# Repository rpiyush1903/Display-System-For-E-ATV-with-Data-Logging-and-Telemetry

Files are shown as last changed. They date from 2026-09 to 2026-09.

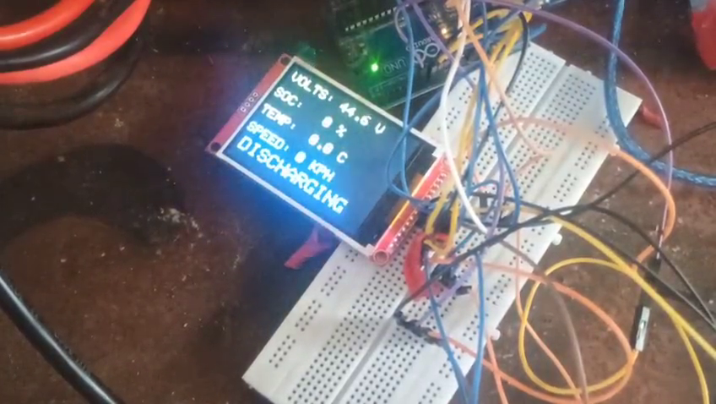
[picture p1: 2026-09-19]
display-test-img.png

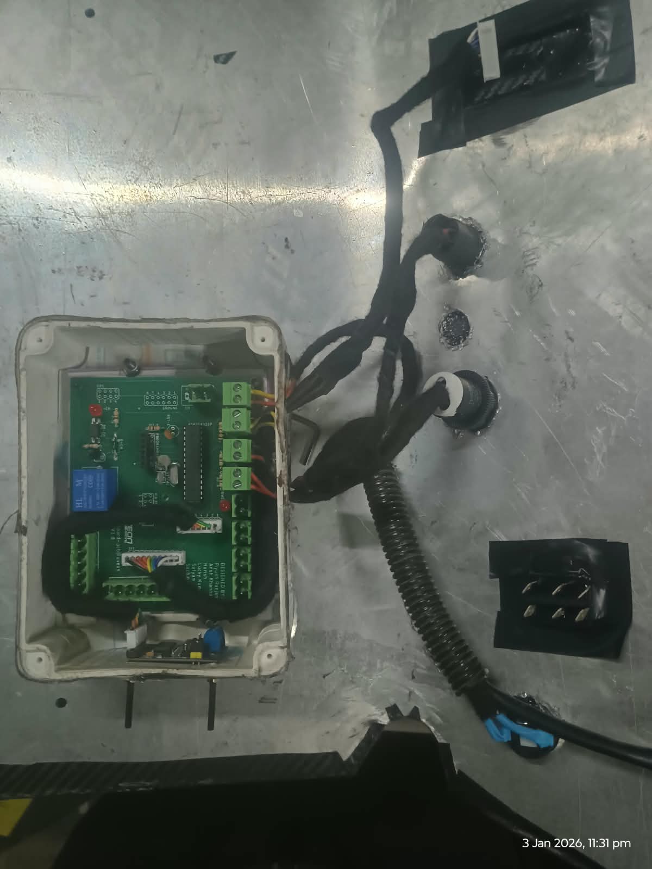
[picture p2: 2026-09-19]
dashboard-pcb-img.jpeg

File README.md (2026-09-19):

# Display and Safety System for an E-ATV Using CAN Bus Communication Protocol

## Description

This project is a custom dashboard and safety unit that I built for our electric All-Terrain Vehicle. It sits between the driver and the battery pack, doing two jobs at once: showing the driver what the battery is doing in real time, and acting as a safety switch that can cut power to the tractive system if something goes wrong.

The unit reads data directly from our JBD Battery Management System over CAN bus and shows it on a TFT display mounted on the dash Pack voltage, current draw (or charge current), state of charge (SoC), and pack temperature. It also drives a relay that can de-energize the main contactors, either automatically when a fault is detected or manually during testing.

Everything runs on an ATMega328P microcontroller, with an MCP2515 module handling the CAN interface, and the whole thing is built onto a custom PCB so it can survive the vibration and environment of off-road racing.

## Why I Built This

When you're racing an e-ATV, the battery pack is both the thing that makes the vehicle go and the thing most likely to cause a serious problem if it's mismanaged. 

**Charging and pack safety.** A lithium pack that's overcharged, over-discharged, or running too hot can fail badly, and on a race vehicle there isn't always someone watching a laptop connected to the BMS. I wanted a hardware safety interlock that sits close to the pack and can isolate it the moment something crosses a safe limit, rather than relying on the driver to notice a problem and react in time. 

Also there should be an hardware safety interlock to prevent simultaneous charging and operation of vehicle ( battery should not get charged when vehicle is ready to drive)

**Driver awareness.** Beyond safety, the driver genuinely needs to know what the battery is doing while driving — voltage, current draw, temperature, and remaining charge. Without this, the driver is flying blind: they don't know if they're pushing the pack too hard, how much charge is left for the rest of a heat, or whether the pack is running hotter than it should. A simple, readable display on the dash solves that, and having it double as a diagnostic tool during pit stops and testing was a natural extension.

Putting both of these on one board also meant fewer separate systems, less wiring, and reduced clutter in the vehicle.

## How I Did It

I started from the JBD BMS's CAN output, since that's already generating the data I needed I didn't want to add extra sensors when the BMS was already measuring everything.

**Reading the BMS over CAN.** I used an MCP2515 CAN controller (SPI interface) to talk to the BMS at 500kbps. The BMS broadcasts on a few standard IDs, and I parsed the ones that matter for the dashboard:

| CAN ID | Data |
| :--- | :--- |
| `0x100` | Pack voltage and current |
| `0x101` | State of charge 
| `0x105` | Pack temperature 

Since the BMS doesn't just keep streaming data forever on its own, I have the microcontroller send a small keep-alive frame (`0x5A`) periodically to the BMS's target IDs, which keeps the connection alive and the data flowing.

**Showing it to the driver.** The parsed values get pushed to a TFT display using the `TFT_eSPI` library, connected over the hardware SPI bus. I set up `User_Setup.h` to match the exact driver and pinout of the display I used, since getting this wrong is the most common reason the display doesn't come up at all.

**The safety side.** A relay is wired to a dedicated GPIO pin (pin 5 in the diagnostic build). HIGH keeps the relay de-energized and power flowing normally; pulling it LOW cuts power by opening the main contactors. This lets the firmware isolate the pack automatically if a reading goes outside safe limits, and it also gives me a manual way to cut power during bench testing without touching the high-voltage wiring directly.

**Putting it on one board.** Once the logic was working on a breadboard, I moved everything onto a custom PCB. The main reason was reliability . An ATV shakes a lot, and loose header connections are a common failure point. I also made sure to physically separate the high-speed SPI lines (display and CAN) from the relay switching lines on the layout, since the relay can introduce electrical noise that was causing flicker on the display and occasional glitches on the CAN bus during earlier tests.

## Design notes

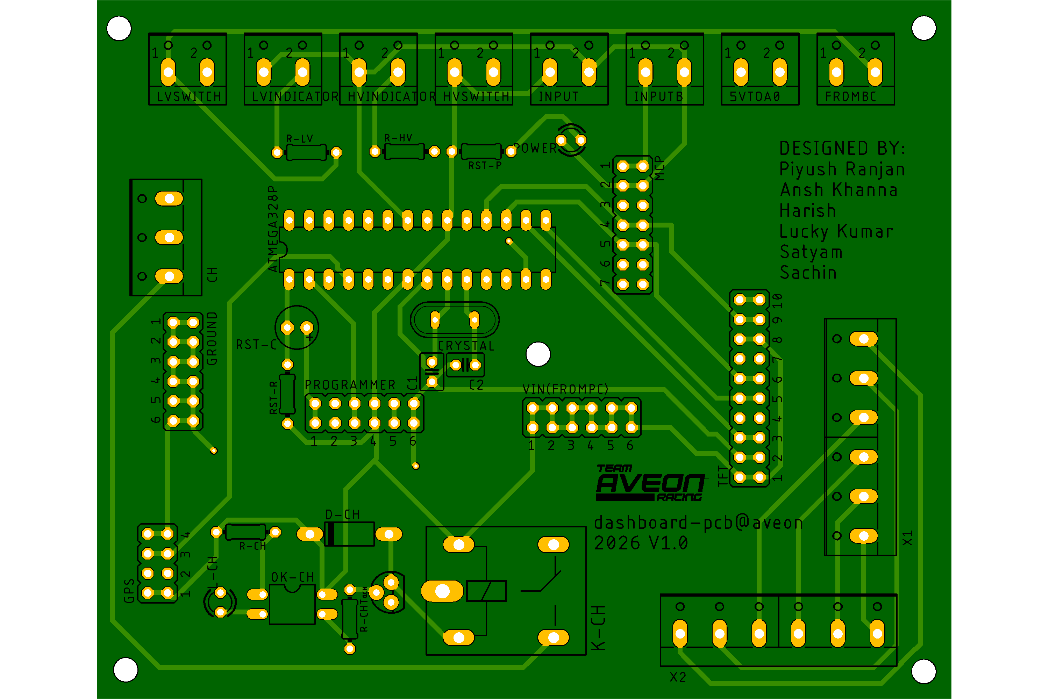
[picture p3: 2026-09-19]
DASHBOARDTOP.png

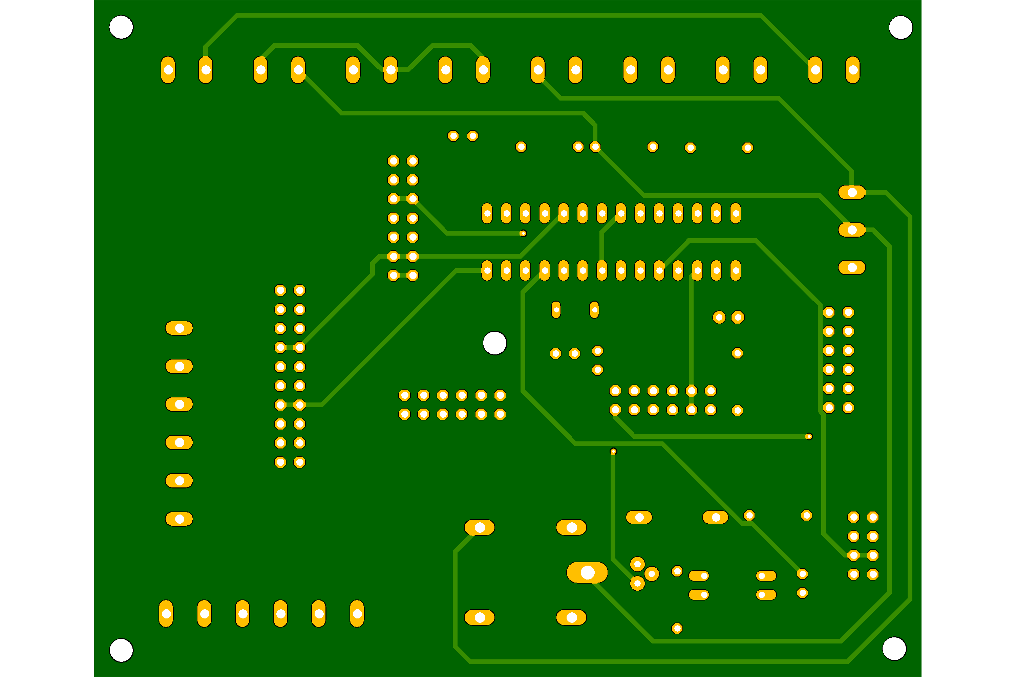
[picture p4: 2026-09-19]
DASHBOARDBOTTOM.png

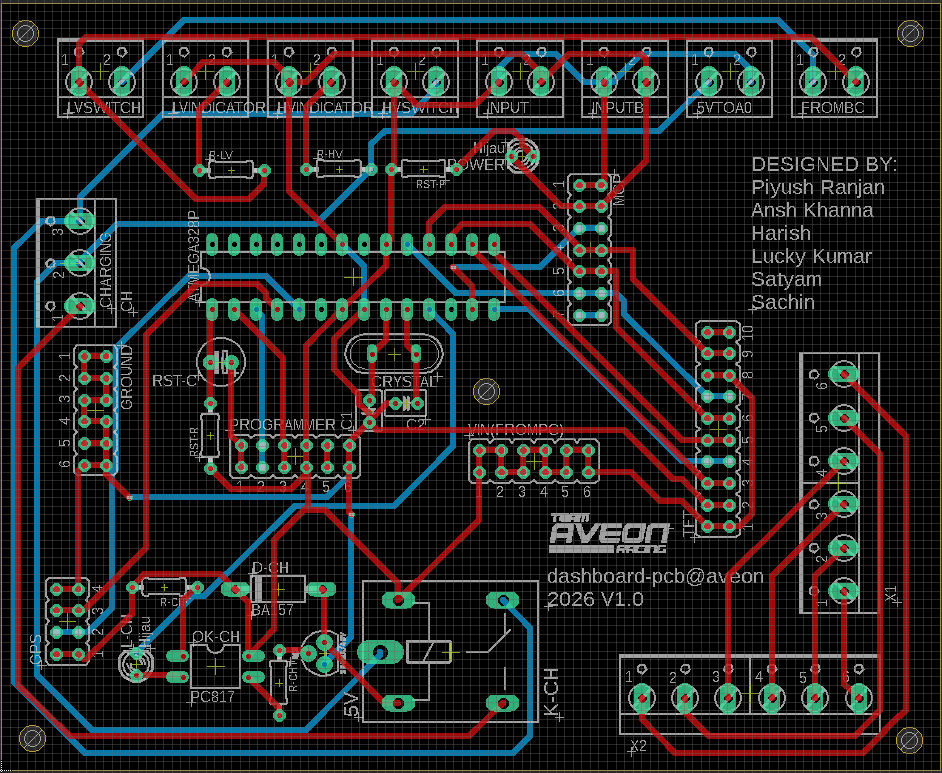
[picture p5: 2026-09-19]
pcb-brdfile.png

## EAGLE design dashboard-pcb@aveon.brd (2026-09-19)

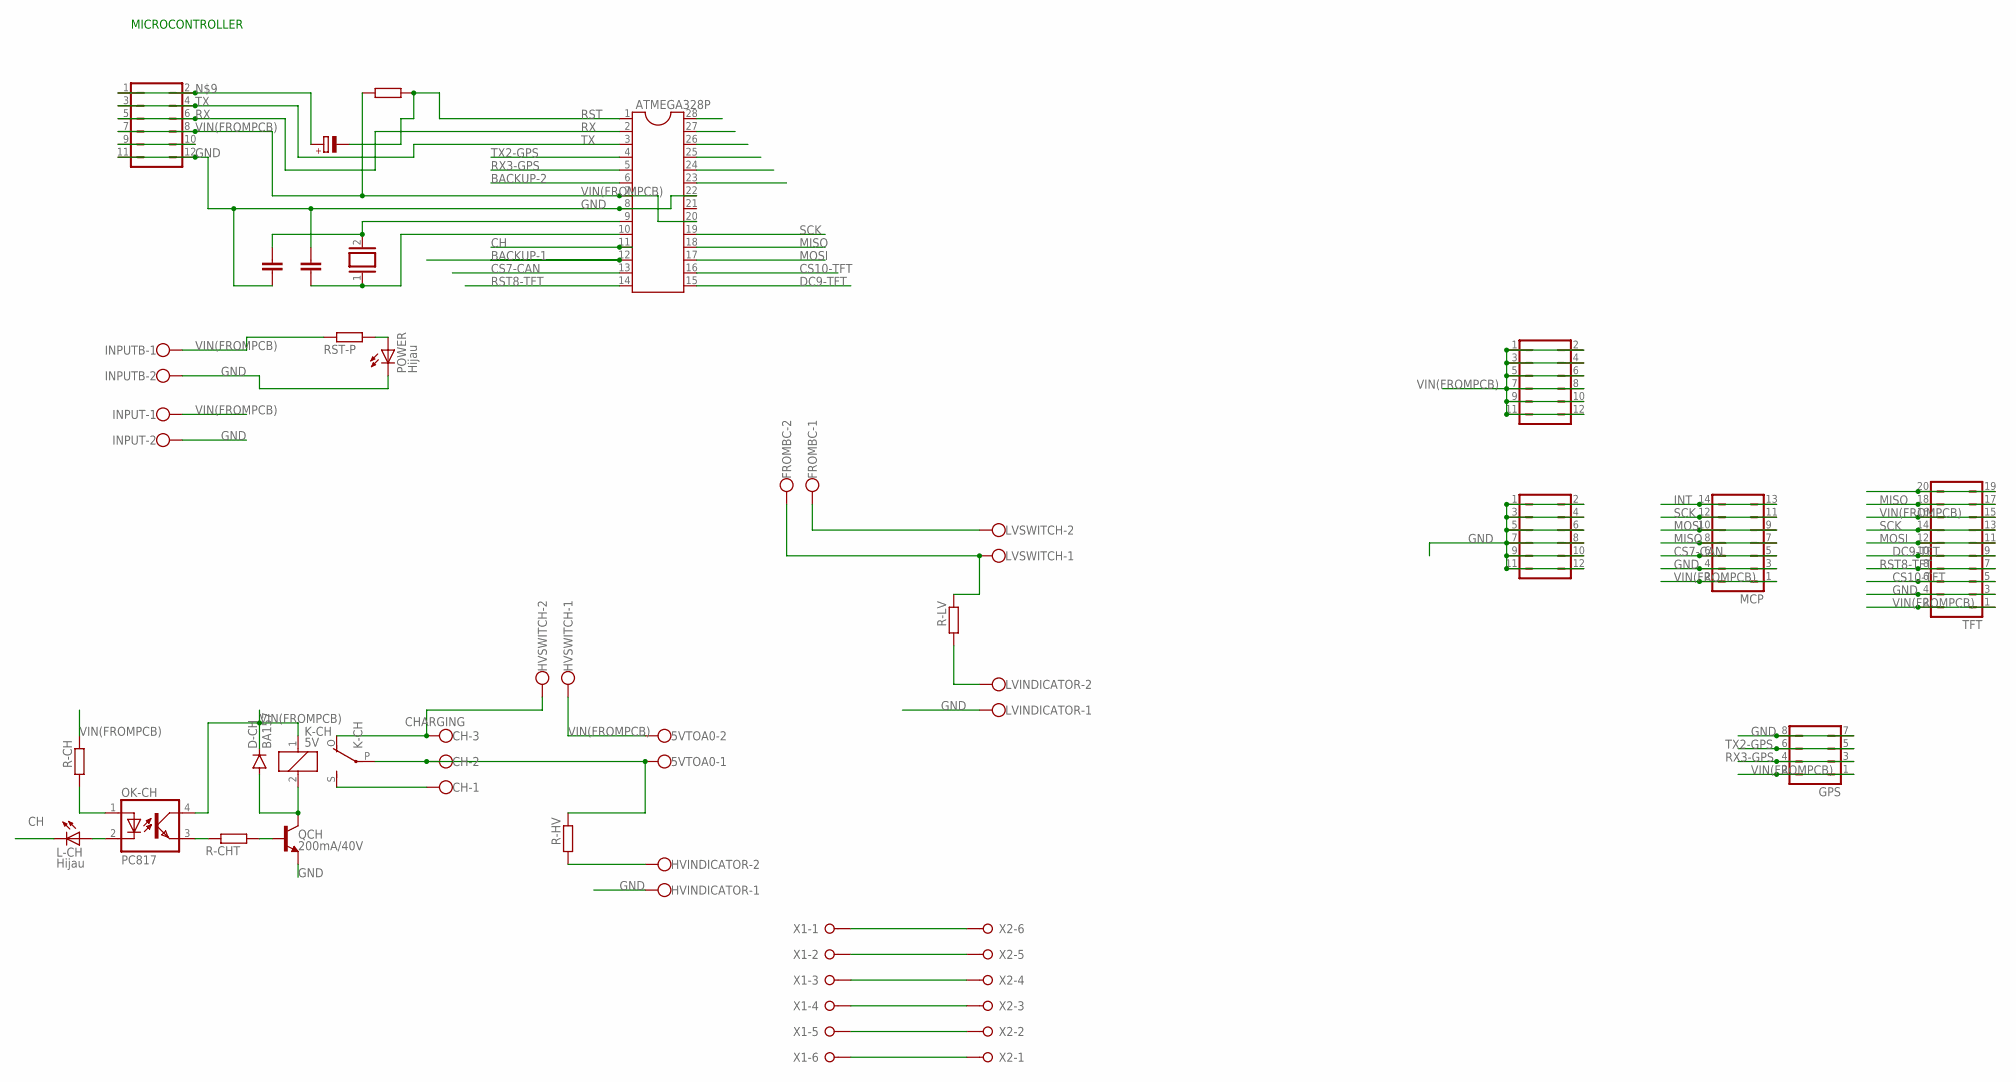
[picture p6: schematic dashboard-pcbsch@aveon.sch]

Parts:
5VTOA0: W237-102
ATMEGA328P: DIL28-3
C1, C2: C-EU025-030X050; C025-030X050
CH: CHARGING; W237-103
CRYSTAL: XTAL/S; QS
D-CH: BA157; P1-10
FROMBC: W237-102
GPS: JP4Q
GROUND: JP6Q
HVINDICATOR: W237-102
HVSWITCH: W237-102
INPUT: W237-102
INPUTB: W237-102
K-CH: 5V; ZF112
L-CH: Hijau; LED3MM
LVINDICATOR: W237-102
LVSWITCH: W237-102
MCP: JP7Q
OK-CH: PC817; DIL04
POWER: Hijau; LED3MM
PROGRAMMER: JP6Q
QCH: 200mA/40V; TO-92
R-CH: R-EU_0204/7; 0204/7
R-CHT: R-EU_0204/7; 0204/7
R-HV: R-EU_0204/7; 0204/7
R-LV: R-EU_0204/7; 0204/7
RST-C: CPOL-EUE2.5-6; E2,5-6
RST-P: R-EU_0204/7; 0204/7
RST-R: R-EU_0204/7; 0204/7
TFT: JP10Q
VIN(FROMPC): JP6Q
X1, X2: W237-06P; W237-6P

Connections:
BACKUP-1: ATMEGA328P.12
BACKUP-2: ATMEGA328P.6
CH: ATMEGA328P.11, L-CH.K (C)
CS7-CAN: ATMEGA328P.13, MCP.5, MCP.6
CS10-TFT: ATMEGA328P.16, TFT.5, TFT.6
DC9-TFT: ATMEGA328P.15, TFT.9, TFT.10
GND: ATMEGA328P.8, ATMEGA328P.22, C1.1, C2.2, GPS.7, GPS.8, GROUND.1, GROUND.2, GROUND.3, GROUND.4, GROUND.5, GROUND.6, GROUND.7, GROUND.8, GROUND.9, GROUND.10, GROUND.11, GROUND.12, HVINDICATOR.1, INPUT.2, INPUTB.2, LVINDICATOR.1, MCP.3, MCP.4, POWER.K (C), PROGRAMMER.11, PROGRAMMER.12, QCH.1 (E), TFT.3, TFT.4
INT: MCP.13, MCP.14
MISO: ATMEGA328P.18, MCP.7, MCP.8, TFT.17, TFT.18
MOSI: ATMEGA328P.17, MCP.9, MCP.10, TFT.11, TFT.12
unnamed: POWER.A, RST-P.1
unnamed: FROMBC.1, LVSWITCH.2
unnamed: FROMBC.2, LVSWITCH.1, R-LV.2
unnamed: LVINDICATOR.2, R-LV.1
unnamed: PROGRAMMER.1, PROGRAMMER.2, RST-C.+
unnamed: ATMEGA328P.9, C1.2, CRYSTAL.2
unnamed: X1.1, X2.6
unnamed: X1.2, X2.5
unnamed: X1.3, X2.4
unnamed: X1.4, X2.3
unnamed: L-CH.A, OK-CH.2 (C)
unnamed: CH.3, HVSWITCH.2, K-CH.O
unnamed: OK-CH.1 (A), R-CH.1
unnamed: OK-CH.3 (EMIT), R-CHT.2
unnamed: D-CH.A, K-CH.2, QCH.3 (C)
unnamed: QCH.2 (B), R-CHT.1
unnamed: CH.1, K-CH.S
unnamed: 5VTOA0.1, CH.2, K-CH.P, R-HV.2
unnamed: X1.5, X2.2
unnamed: HVINDICATOR.2, R-HV.1
unnamed: X1.6, X2.1
unnamed: TFT.19, TFT.20
unnamed: ATMEGA328P.10, C2.1, CRYSTAL.1
unnamed: PROGRAMMER.9, PROGRAMMER.10
RST: ATMEGA328P.1, RST-C.-, RST-R.2
RST8-TFT: ATMEGA328P.14, TFT.7, TFT.8
RX: ATMEGA328P.2, PROGRAMMER.5, PROGRAMMER.6
RX3-GPS: ATMEGA328P.5, GPS.3, GPS.4
SCK: ATMEGA328P.19, MCP.11, MCP.12, TFT.13, TFT.14
TX: ATMEGA328P.3, PROGRAMMER.3, PROGRAMMER.4
TX2-GPS: ATMEGA328P.4, GPS.5, GPS.6
VIN(FROMPCB): 5VTOA0.2, ATMEGA328P.7, ATMEGA328P.20, D-CH.C, GPS.1, GPS.2, HVSWITCH.1, INPUT.1, INPUTB.1, K-CH.1, MCP.1, MCP.2, OK-CH.4 (COL), PROGRAMMER.7, PROGRAMMER.8, R-CH.2, RST-P.2, RST-R.1, TFT.1, TFT.2, TFT.15, TFT.16, VIN(FROMPC).1, VIN(FROMPC).2, VIN(FROMPC).3, VIN(FROMPC).4, VIN(FROMPC).5, VIN(FROMPC).6, VIN(FROMPC).7, VIN(FROMPC).8, VIN(FROMPC).9, VIN(FROMPC).10, VIN(FROMPC).11, VIN(FROMPC).12

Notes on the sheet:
MICROCONTROLLER

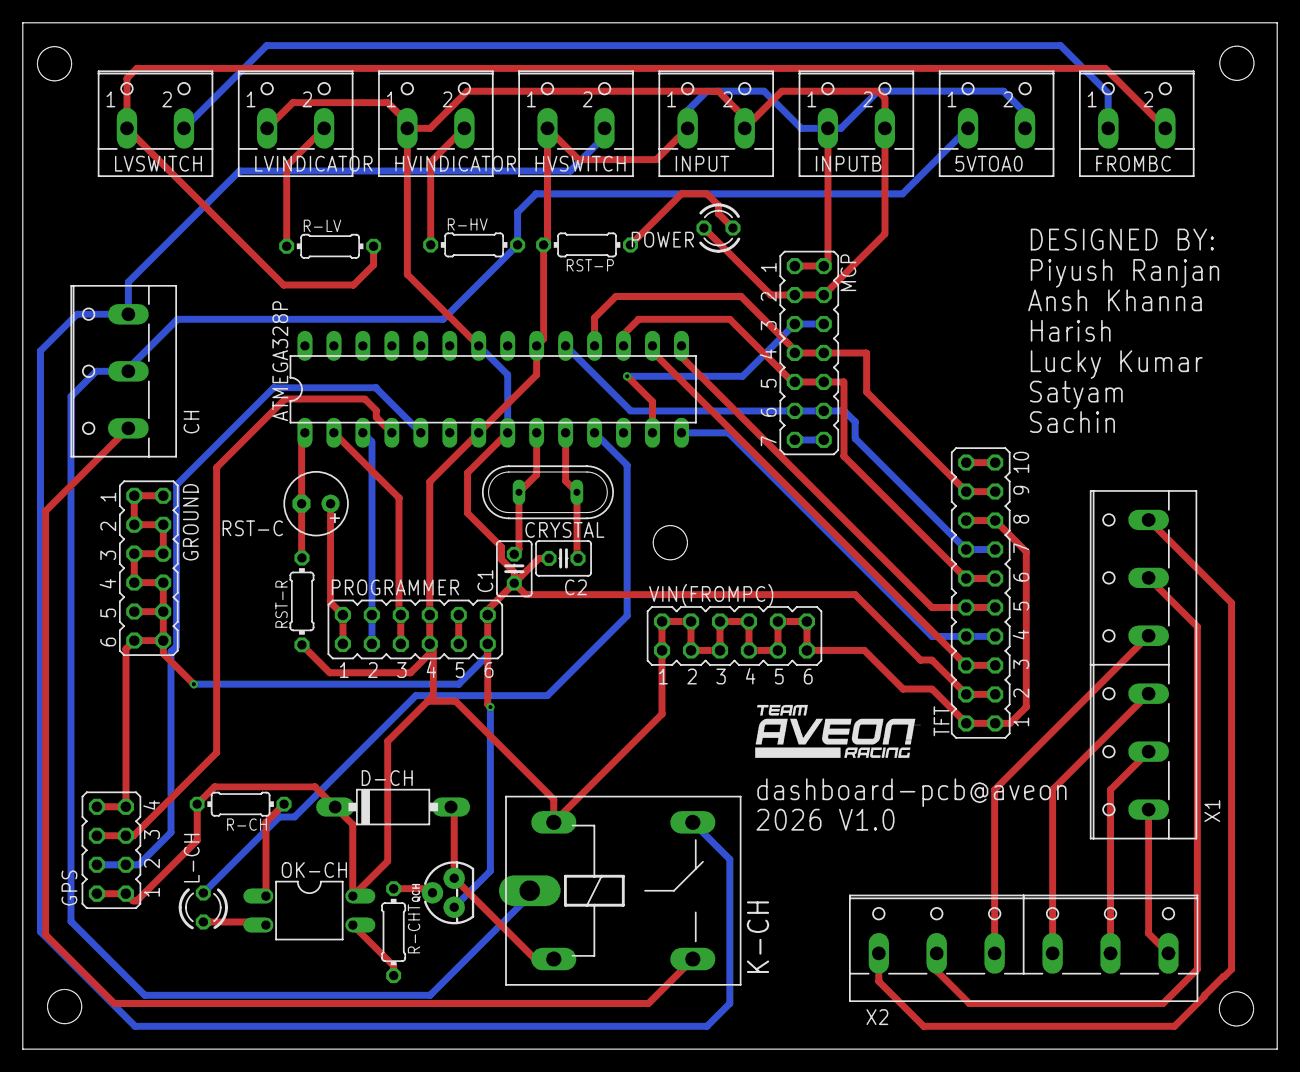
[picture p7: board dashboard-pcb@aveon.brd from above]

Board: 2 copper layers, 110.0 x 90.0 mm, 34 parts (0 on the bottom side), 40 nets.

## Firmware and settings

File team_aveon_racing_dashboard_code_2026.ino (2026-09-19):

/*
  Aveon Racing - JBD BMS Dashboard (2.8" CENTERED VERSION)
  
  - Controller: ATmega328P (Arduino Uno)
  - Display: ST7789 / ILI9341 (320x240 Landscape)
  - CAN Bus: MCP2515 (CS Pin 7)
  - Safety: Relay on Pin 5 (Active LOW)
  
  UPDATES:
  1. Centered Logo for 320px wide screens.
  2. Colors: TEAM/RACING = White, AVEON = Dark Green.
  3. Dashboard layout expanded to fill 2.8" screen.
*/

#include <SPI.h>
#include <TFT_eSPI.h>
#include <mcp_can.h>
#include <avr/pgmspace.h>

// --- Load Custom Font ---
#define RACING_FONT &FreeSansBold12pt7b 

// --- Pin Definitions ---
const int MCP_CS_PIN = 7;
const int RELAY_PIN  = 5; // Safety Relay (Active LOW)

// --- CAN IDs ---
#define CAN_ID_VOLT_CURR 0x100 
#define CAN_ID_SOC       0x101
#define CAN_ID_TEMP      0x105

// --- Global Objects ---
TFT_eSPI tft = TFT_eSPI();
MCP_CAN mcp2515(MCP_CS_PIN);
SPISettings mcpSPISettings(10000000, MSBFIRST, SPI_MODE0);

// --- Data Variables ---
float rawVoltage = 0.0;
float smoothedVoltage = 0.0;
float current = 0.0;
int   soc = 0;
float tempNTC1 = 0.0;
bool  isCharging = false;
bool  newDataBMS = false;

// --- Screen Constants ---
// 2.8" Screens are usually 320x240 in Landscape
const int SCREEN_W = 320;
const int SCREEN_H = 240;
int centerX = SCREEN_W / 2; // Will be calculated in setup

// --- Layout Constants ---
const int BORDER_COLOR = TFT_CYAN;
const int TEXT_COLOR   = TFT_WHITE;
const int ROW_VOLTS = 50; 
const int ROW_SOC   = 110;
const int ROW_TEMP  = 170;

// Adjusted columns for wider 320px screen
const int COL_LABEL = 20;  // Labels slightly indented
const int COL_DATA  = 160; // Data numbers moved to the right side

// --- Timing ---
unsigned long lastCANRequest = 0;
unsigned long lastDisplayUpdate = 0;
const long canRequestInterval = 1000;   
const long displayUpdateInterval = 250; 

// ==========================================
//   HELPER FUNCTIONS 
// ==========================================
void drawStaticInterface();
void updateDisplayValues();
void parseBMSData(long id, unsigned char data[8]);
void updateSafetyRelay();

// ==========================================
//   MAIN SETUP
// ==========================================
void setup() {
  // 1. Init Relay (Fail-Safe: HIGH)
  pinMode(RELAY_PIN, OUTPUT);
  digitalWrite(RELAY_PIN, HIGH); 

  // 2. Init TFT
  tft.init();
  tft.setRotation(1); // Landscape
  tft.fillScreen(TFT_BLACK);
  
  // Calculate true center based on actual screen width
  centerX = tft.width() / 2;

  // =========================================
  //   STARTUP SEQUENCE (CENTERED)
  // =========================================
  
  tft.setTextDatum(MC_DATUM); // Set alignment to Middle Center
  
  // Draw "TEAM" (Small, White)
  tft.setTextSize(1);
  tft.setFreeFont(RACING_FONT);
  tft.setTextColor(TFT_WHITE, TFT_BLACK); 
  tft.drawString("TEAM", centerX, 60);

  // Draw "AVEON" (Large, Dark Green)
  tft.setTextSize(2); // Double size
  tft.setTextColor(TFT_DARKGREEN, TFT_BLACK);
  tft.drawString("AVEON", centerX, 100);

  // Draw "RACING" (Small, White)
  tft.setTextSize(1);
  tft.setTextColor(TFT_WHITE, TFT_BLACK);
  tft.drawString("RACING", centerX, 140);
  
  // Draw Init Status
  tft.setFreeFont(NULL); // Standard font
  tft.setTextSize(1);
  tft.setTextColor(TFT_WHITE, TFT_BLACK);
  tft.drawString("Initializing CAN Bus...", centerX, 180);

  // 3. Init CAN
  SPI.beginTransaction(mcpSPISettings);
  while (mcp2515.begin(MCP_ANY, CAN_500KBPS, MCP_8MHZ) != CAN_OK) {
    SPI.endTransaction();
    
    // Update status (Centered)
    tft.fillRect(0, 170, tft.width(), 30, TFT_BLACK);
    tft.setTextColor(TFT_RED, TFT_BLACK);
    tft.drawString("CAN FAIL. Retrying...", centerX, 180);
    
    delay(500);
    SPI.beginTransaction(mcpSPISettings);
  }
  SPI.endTransaction();
  
  SPI.beginTransaction(mcpSPISettings);
  mcp2515.setMode(MCP_NORMAL);
  SPI.endTransaction();

  // Show Success
  tft.fillRect(0, 170, tft.width(), 30, TFT_BLACK);
  tft.setTextColor(TFT_GREEN, TFT_BLACK);
  tft.drawString("CAN CONNECTED!", centerX, 180);
  delay(1500); 
  
  // =========================================
  //   START DASHBOARD
  // =========================================
  tft.fillScreen(TFT_BLACK);
  tft.setTextDatum(TL_DATUM); // Reset alignment to Top-Left for dashboard
  drawStaticInterface();
}

// ==========================================
//   MAIN LOOP
// ==========================================
void loop() {
  unsigned long now = millis();

  // --- TASK 1: BMS Request ---
  if (now - lastCANRequest >= canRequestInterval) {
    lastCANRequest = now;
    byte msg[1] = {0x5A};
    SPI.beginTransaction(mcpSPISettings);
    mcp2515.sendMsgBuf(CAN_ID_VOLT_CURR, 0, 1, msg);
    delay(5); 
    mcp2515.sendMsgBuf(CAN_ID_SOC, 0, 1, msg);
    delay(5);
    mcp2515.sendMsgBuf(CAN_ID_TEMP, 0, 1, msg);
    SPI.endTransaction();
  }

  // --- TASK 2: Receive CAN ---
  SPI.beginTransaction(mcpSPISettings);
  if (mcp2515.checkReceive() == CAN_MSGAVAIL) {
    long canId;
    unsigned char len;
    unsigned char buf[8];
    mcp2515.readMsgBuf(&canId, &len, buf);
    parseBMSData(canId, buf);
    newDataBMS = true;
  }
  SPI.endTransaction();

  // --- TASK 3: Safety Logic ---
  updateSafetyRelay();

  // --- TASK 4: Update Display ---
  if (now - lastDisplayUpdate >= displayUpdateInterval) {
    lastDisplayUpdate = now;
    
    if(rawVoltage > 1.0) { 
        smoothedVoltage = (smoothedVoltage * 0.8) + (rawVoltage * 0.2);
    }
    
    updateDisplayValues();
  }
}

// ==========================================
//   FUNCTIONS
// ==========================================

void updateSafetyRelay() {
  if (isCharging) {
    digitalWrite(RELAY_PIN, LOW); 
  } else {
    digitalWrite(RELAY_PIN, HIGH);
  }
}

void parseBMSData(long id, unsigned char data[8]) {
  switch (id) {
    case CAN_ID_VOLT_CURR:
      rawVoltage = ((data[0] << 8) | data[1]) * 0.01;
      current = (int16_t)((data[2] << 8) | data[3]) * 0.01;
      
      if (current > 0.5) {
        isCharging = true;
      } else {
        isCharging = false;
      }
      break;

    case CAN_ID_SOC:
      soc = (data[4] << 8) | data[5];
      break;
      
    case CAN_ID_TEMP:
      float tempK = ((data[0] << 8) | data[1]) * 0.1;
      tempNTC1 = tempK - 273.15;
      break;
  }
}

void drawStaticInterface() {
  // Draw Borders (Dynamic Width)
  int w = tft.width();
  int h = tft.height();
  
  tft.drawRect(0, 0, w, h, BORDER_COLOR);
  tft.drawRect(1, 1, w-2, h-2, BORDER_COLOR); 

  // Draw Separator Lines
  tft.drawLine(10, 65, w-10, 65, TFT_DARKGREY);  
  tft.drawLine(10, 125, w-10, 125, TFT_DARKGREY); 
  tft.drawLine(10, 185, w-10, 185, TFT_DARKGREY); 

  // Draw Labels
  tft.setTextColor(TFT_LIGHTGREY, TFT_BLACK); 
  tft.setFreeFont(RACING_FONT); 
  tft.setTextSize(1);

  tft.setCursor(COL_LABEL, ROW_VOLTS);
  tft.print("VOLT");
  tft.setCursor(COL_LABEL, ROW_SOC);
  tft.print("SOC");
  tft.setCursor(COL_LABEL, ROW_TEMP);
  tft.print("TEMP");
}

void updateDisplayValues() {
  tft.setFreeFont(RACING_FONT); 
  tft.setTextColor(TEXT_COLOR, TFT_BLACK);
  tft.setTextSize(1);

  // Update Voltage
  // Erase box is wider now for 320px screen
  tft.fillRect(COL_DATA, ROW_VOLTS - 25, 140, 30, TFT_BLACK);
  tft.setCursor(COL_DATA, ROW_VOLTS);
  tft.print(smoothedVoltage, 1);
  tft.print(" V");

  // Update SOC
  tft.fillRect(COL_DATA, ROW_SOC - 25, 140, 30, TFT_BLACK);
  if (soc < 20) tft.setTextColor(TFT_RED, TFT_BLACK);
  else tft.setTextColor(TFT_WHITE, TFT_BLACK);
  tft.setCursor(COL_DATA, ROW_SOC);
  tft.print(soc);
  tft.print(" %");

  // Update Temp
  tft.fillRect(COL_DATA, ROW_TEMP - 25, 140, 30, TFT_BLACK);
  if (tempNTC1 > 55) tft.setTextColor(TFT_RED, TFT_BLACK);
  else tft.setTextColor(TFT_WHITE, TFT_BLACK);
  tft.setCursor(COL_DATA, ROW_TEMP);
  tft.print(tempNTC1, 0);
  tft.print(" C");

  // Update Status
  tft.fillRect(10, 195, tft.width()-20, 40, TFT_BLACK);
  tft.setTextDatum(MC_DATUM);  
  
  if (isCharging) {
    tft.setTextColor(TFT_GREEN, TFT_BLACK);
    tft.drawString("CHARGING", centerX, 215); // Centered
  } else {
    tft.setTextColor(TFT_ORANGE, TFT_BLACK);
    tft.drawString("DISCHARGING", centerX, 215); // Centered
  }
  tft.setTextDatum(TL_DATUM); 
}

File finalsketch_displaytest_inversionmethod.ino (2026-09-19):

/*
  TFT_eSPI Library Test for ST7789 (320x240)

  This sketch will run all tests in landscape mode.
  It relies on your User_Setup.h file being
  correctly configured.
*/
#include <SPI.h>
#include <TFT_eSPI.h> // Include the configured library

// Create a TFT_eSPI object
TFT_eSPI tft = TFT_eSPI();

void setup() {
  Serial.begin(9600);
  Serial.println("TFT_eSPI ST7789 Test (Landscape)");

  tft.init(); // Initialize the library
  
  // --- LANDSCAPE MODE ---
  // setRotation(1) or setRotation(3) will give 320x240.
  // If this is upside-down, change 1 to 3.
  tft.setRotation(1); 

  // --- USER REQUEST: Set background to BLACK ---
  // This should now work with TFT_INVERSION_OFF
  tft.fillScreen(TFT_BLACK); 
  Serial.println("Screen set to black.");
  delay(500);

  // --- Start Test Sequence ---

  // Test 1: Text
  testText();
  delay(2000);

  // Test 2: Lines
  testLines(TFT_CYAN);
  delay(1000);

  // Test 3: Rectangles
  testRects(TFT_GREEN);
  delay(1000);

  // Test 4: Circles
  testCircles(TFT_MAGENTA);
  delay(1000);

  // Test 5: Screen Fills (R, G, B)
  testFillScreen();
  delay(1000);

  // --- Test Complete ---
  tft.fillScreen(TFT_BLACK);
  tft.setCursor(40, 100); // Centered for 320x240
  tft.setTextColor(TFT_GREEN);
  tft.setTextSize(3);
  
  // This text will now print correctly on one line
  tft.println("TEST COMPLETE"); 
  Serial.println("Test complete.");
}

void loop() {
  // The test runs once in setup(), so loop is empty.
}

// --- Helper Test Functions ---
// All functions now use tft.width() = 320 and tft.height() = 240

void testText() {
  tft.fillScreen(TFT_BLACK);
  tft.setCursor(0, 0);
  tft.setTextColor(TFT_WHITE);
  tft.setTextSize(2);
  tft.println("Hello World!");
  tft.println("This is ST7789 landscape.");

  tft.setTextColor(TFT_YELLOW);
  tft.setTextSize(3);
  tft.println(1234.56);

  tft.setTextColor(TFT_RED);
  tft.setTextSize(4);
  tft.println("TEST!");

  tft.setTextColor(TFT_BLUE);
  tft.setTextSize(1);
  tft.println("Testing complete.");
}

void testLines(uint16_t color) {
  tft.fillScreen(TFT_BLACK);
  // tft.width() is 320
  // tft.height() is 240
  for (int16_t x = 0; x < tft.width(); x += 8) {
    tft.drawLine(0, 0, x, tft.height() - 1, color);
  }
  for (int16_t y = 0; y < tft.height(); y += 8) {
    tft.drawLine(0, 0, tft.width() - 1, y, color);
  }
}

void testRects(uint16_t color) {
  tft.fillScreen(TFT_BLACK);
  tft.drawRect(tft.width() / 4, tft.height() / 4, tft.width() / 2, tft.height() / 2, color);
  delay(500);
  tft.fillRect(tft.width() / 3, tft.height() / 3, tft.width() / 3, tft.height() / 3, color);
}

void testCircles(uint16_t color) {
  tft.fillScreen(TFT_BLACK);
  tft.drawCircle(tft.width() / 2, tft.height() / 2, 50, color);
  delay(500);
  tft.fillCircle(tft.width() / 2, tft.height() / 2, 25, color);
}

void testFillScreen() {
  tft.fillScreen(TFT_RED);
  Serial.println("RED");
  delay(500);
  tft.fillScreen(TFT_GREEN);
  Serial.println("GREEN");
  delay(500);
  tft.fillScreen(TFT_BLUE);
  Serial.println("BLUE");
  delay(500);
  tft.fillScreen(TFT_BLACK);
  Serial.println("BLACK");
  delay(500);
}

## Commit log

2026-09-19 Remove schematics and PCB layout section
    Removed schematics and PCB layout section from README.
2026-09-19 Revise CAN ID table and remove pin reference
    Updated the table format for CAN ID data and removed the pin reference section.

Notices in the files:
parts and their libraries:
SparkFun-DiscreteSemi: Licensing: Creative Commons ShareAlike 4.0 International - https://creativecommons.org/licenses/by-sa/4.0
